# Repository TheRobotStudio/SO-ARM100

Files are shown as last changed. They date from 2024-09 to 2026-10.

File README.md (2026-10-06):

<div align="center">

   <h1>Standard Open SO-100 & SO-101 Arms</h1>
   <div style="display: flex; gap: 1rem; justify-content: center; align-items: center;" >
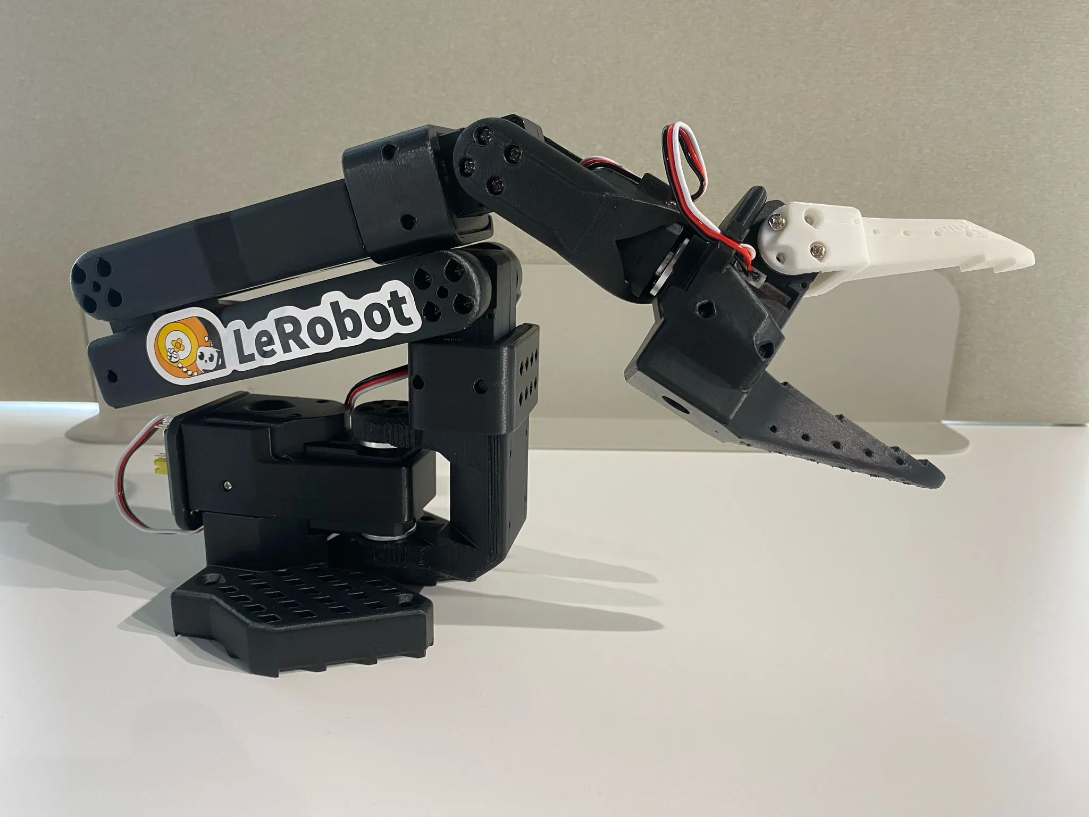
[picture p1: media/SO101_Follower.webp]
SO-101 follower arm
   
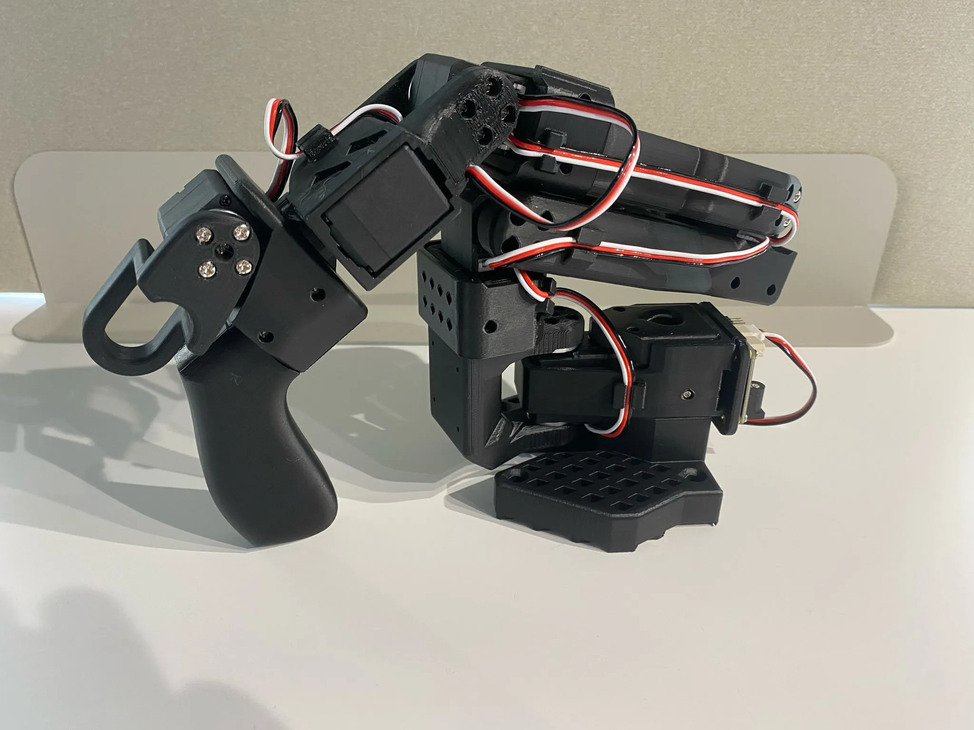
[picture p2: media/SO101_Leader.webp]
SO-101 leader arm
   
</div>

<h2>
    <p>Build Your Own SO-101 Robot!</p>
</h2>

The SO‑101 is the next‑generation version of the SO‑100 robot arm, originally designed by the [RobotStudio](https://www.therobotstudio.com) in collaboration with [Hugging Face](https://huggingface.co/lerobot). It has improved wiring, is easier to assemble (no gear removal) and uses updated motors for the leader arm.

These arms are designed to work seamlessly with the open‑source 🤗 LeRobot library. Join our community on [Discord](https://discord.gg/ggrqhPTsMe) to collaborate on both hardware and software, and help make end‑to‑end AI for robotics more accessible.

</div>

### Documentation 📖
- For the SO‑101 docs, follow this page further.
- Here you can find the [SO‑100 docs](SO100.md) which is deprecated.

### Getting Your Own SO‑101 
You have two options:
- **Build it Yourself**
   - Source the components from the [Bill of Materials](#sourcing-parts).
   - 3D print the parts (or order the 3D printed parts), explained in [Printing the Parts](#printing-the-parts).
   - Follow our [Assembly Guide](https://huggingface.co/docs/lerobot/so101).
- **Buy a Kit**
   - Buy assembled arms or a parts kit from one of the vendors [here](#kits).
   - Optionally follow our [Assembly Guide](https://huggingface.co/docs/lerobot/so101).

### Setup with LeRobot 🤗
After sourcing all parts you can setup your SO-101 with LeRobot [tutorial](https://huggingface.co/docs/lerobot/so101). 

### Optional Hardware 🔧
This repository also includes a range of optional hardware designs such as a raised leader base and different camera mounts. Here you can explore the [full list](#optional-hardware).

## Kits

You can find all optional for SO-100/SO-101 kits here:

- from Seeed studio :earth_africa: [International](https://www.seeedstudio.com/SO-ARM100-Low-Cost-AI-Arm-Kit.html) or :cn: [China](https://item.taobao.com/item.htm?id=878010637397&skuId=5915703371829&spm=a213gs.v2success.0.0.4cbf4831mkqWLn) or :jp: [Akizuki Denshi](https://akizukidenshi.com/catalog/g/g131169/) or [Aliexpress](https://www.aliexpress.com/item/3256808696884714.html?gatewayAdapt=4itemAdapt) (They include **3d printed kits**)
- from WowRobo :earth_africa: [International](https://shop.wowrobo.com/products/so-arm101-diy-kit-assembled-version-1) or :cn: [China](https://item.taobao.com/item.htm?ft=t&id=860171734711) (They include **assembled** versions)
- from RobotEd :switzerland: [Switzerland](https://roboted.ch/en/shop/so-101-robot-arm-kit) (They include **3d printed frame kits**, **electronics kits** and **complete arm kits**)
- from Robonine :earth_africa: [International](https://robonine.com/shop/so-arm101-black-white-robotic-arm-kit/) (They include **parts** kits with a wrist camera and an ArUco cube)
- from PartaBot :us: [US](https://partabot.com) (They include **assembled** versions, and also sell LeKiwi and Koch robots)
- from ForgeMotion Labs :us: [US](https://forgemotionlabs.com/products) or [Amazon US](https://www.amazon.com/s?me=A3TE39P97BKL59) (They include **3d printed frame kits**, **electronics kits** and **complete arm kits**)
- from RoboSEasy :kr: [South Korea](https://smartstore.naver.com/roboseasy)
- from NeoBot :cn: [China](https://item.taobao.com/item.htm?ft=t&id=957685951340)
- from Autodiscovery :eu: [EU](https://autodiscovery.eu/en/products/so-101-kit??utm_source=hf&utm_medium=shop&utm_content=web)

Additionally you can find SO-100 follower arm kit (without leader arm) on [Phospho](https://robots.phospho.ai). It can be especially useful if you own a VR headset.

## Sourcing Parts

The follower and leader arm for this teleoperation setup will almost the same off the shelf parts (except for the motors). If you plan on creating the classic teleoperation set up to be used with the `LeRobot` library please buy from the Parts for Two Arms below. 

We only have links for US, EU, CN, and JP for now. If you find links for other countries, please create an issue or PR so that we add them to the list. Note that prices and items may vary depending on geographic location.

> [!IMPORTANT]  
> The STS3215 motors for the follower arm comes in two sizes. The 7.4V has a stall torque of 16.5kg.cm at 6V (and likely slightly less for a 5V power supply). The 12V version has a stall torque of 30kg.cm. While we found the 7.4V to be sufficient, if you would like more powerful motors you can buy the 12V version [here](https://www.alibaba.com/product-detail/6PCS-12V-30KG-STS3215-High-Torque_1601216757543.html). Note if you do this, you will also have to buy a 12V 5A+ power supply instead of a 5V one. The leader arm is always 7.4V for the SO101.

#### Parts For Two Arms (Follower and Leader Setup):

| Part | Amount | Unit Cost (US) | Buy US | Unit Cost (EU) | Buy EU | Unit Cost (RMB) | Buy CN | Unit Cost (JPY) | Buy JP |
| --- | --- | --- | --- | --- | --- | --- | --- | --- | --- |
| STS3215 Servo 7.4V, 1/345 gear (C001) **<sup>[2](#leaderbundle)</sup>  | 7 | $13.89 | [Alibaba](https://www.alibaba.com/product-detail/Top-Seller-Low-Cost-Feetech-STS3215_1600999461525.html) | €12.2 | [Alibaba](https://www.alibaba.com/product-detail/Top-Seller-Low-Cost-Feetech-STS3215_1600999461525.html) | ￥97.72 | [TaoBao](https://item.taobao.com/item.htm?id=712179366565&skuId=5268252241438)  | ￥2,980 | [Akizuki Denshi](https://akizukidenshi.com/catalog/g/g116312/)  |
| STS3215 Servo 7.4V, 1/191 gear (C044) **<sup>[2](#leaderbundle)</sup> | 2 | $13.89 | [Alibaba](https://www.alibaba.com/product-detail/Feetech-STS3215-SO-ARM101-Servo-7_1601430747897.html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) | €12.2 | [Alibaba](https://www.alibaba.com/product-detail/Feetech-STS3215-SO-ARM101-Servo-7_1601430747897.html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) | ￥97.72 | -  | ￥2,980 | [Akizuki Denshi](https://akizukidenshi.com/catalog/g/g131131/)  |
| STS3215 Servo 7.4V, 1/147 gear (C046) **<sup>[2](#leaderbundle)</sup> | 3 | $13.89 | [Alibaba](https://www.alibaba.com/product-detail/Feetech-STS3215-SO-ARM101-Servo-7_1601430760797.html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) | €12.2 | [Alibaba](https://www.alibaba.com/product-detail/Feetech-STS3215-SO-ARM101-Servo-7_1601430760797.html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) | ￥97.72 | -  | ￥2,980 | [Akizuki Denshi](https://akizukidenshi.com/catalog/g/g131132/)  |
| Motor Control Board | 2 | $10.6 | [Amazon](https://www.amazon.com/Waveshare-Integrates-Control-Circuit-Supports/dp/B0CTMM4LWK/) | €11.4 | [Amazon](https://www.amazon.fr/-/en/dp/B0CJ6TP3TP/) | ￥27 | [TaoBao](https://detail.tmall.com/item.htm?id=738817173460&skuId=5096283384143) | ￥980 | [Akizuki Denshi](https://akizukidenshi.com/catalog/g/g131227/)  |
| USB-C Cable 2 pcs | 1 | $7 | [Amazon](https://www.amazon.com/Charging-etguuds-Charger-Braided-Compatible/dp/B0B8NWLLW2/?th=1) | €7 | [Amazon](https://www.amazon.fr/dp/B07BNF842T/) | ￥23.9\*2 | [TaoBao](https://detail.tmall.com/item.htm?id=44425281296&skuId=5611379016222)  | ￥1,498 | [Amazon](https://www.amazon.co.jp/dp/B0C3H9L6KZ)  |
| Power Supply | 2 | $10 | [Amazon](https://www.amazon.com/Facmogu-Switching-Transformer-Compatible-5-5x2-1mm/dp/B087LY41PV/) | €15.7 | [Amazon](https://www.amazon.fr/-/en/dp/B01HRR9GY4/) | ￥22.31 | [TaoBao](https://item.taobao.com/item.htm?id=544824248494&skuId=4974994129990)  | ￥1,550 | [Akizuki Denshi](https://akizukidenshi.com/catalog/g/g106238/)  |
| Table Clamp 4pcs | 1 | $9 | [Amazon](https://www.amazon.com/TAODAN-Trigger-Ratchet-Woodworking-Processes/dp/B0DJNXF8WH?rps=1&sr=1-18) | €9.7 | [Amazon](https://www.amazon.fr/Connex-COXT865210-Lot-Serre-joints-bricolage/dp/B00NA3T2CQ) | ￥5.2*4 | [TaoBao](https://detail.tmall.com/item.htm?id=801399113134&skuId=5633627126649) | ￥2,200 | [Amazon](https://www.amazon.co.jp/dp/B0DJNXF8WH)  |
| Screwdriver Set<sup>[1](#myfootnote1)</sup> | 1 | $6 | [Amazon](https://www.amazon.com/Precision-Phillips-Screwdriver-Electronics-Computer/dp/B0DB227RTH) | €9 | [Amazon](https://www.amazon.fr/Vinabo-Magnétique-Electronique-Réparation-Informatique/dp/B0BNQBNFFJ) | ￥14.9 | [TaoBao](https://detail.tmall.com/item.htm?id=675684600845&skuId=4856851392176) | ￥500 | [Amazon](https://www.amazon.co.jp/dp/B01MDNJVMN)  |
| Total | --- | $229.88 | --- | €226.3 | --- | ￥1343.16 | --- | ￥44,530 | --- |

<a name="leaderbundle">2</a>: You can buy **all six STS3215 servos needed for the SO-101 leader arm**  
(3 × 1/147 gear (C046), 2 × 1/191 gear (C044), 1 × 1/345 gear (C001)) in a single bundle on [Alibaba](https://www.alibaba.com/product-detail/6PCS-7-4V-STS3215-Servos-for_1601428584027.html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).

#### Parts for One Follower Arm:

| Part | Amount | Unit Cost (US) | Buy US | Unit Cost (EU) | Buy EU | Unit Cost (RMB) | Buy CN | Unit Cost (JPY) | Buy JP |
| --- | --- | --- | --- | --- | --- | --- | --- | --- | --- |
| STS3215 Servo 7.4V, 1/345 gear (C001) | 6 | $13.89 | [Alibaba](https://www.alibaba.com/product-detail/Top-Seller-Low-Cost-Feetech-STS3215_1600999461525.html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) | €12.2 | [Alibaba](https://www.alibaba.com/product-detail/Top-Seller-Low-Cost-Feetech-STS3215_1600999461525.html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) | ￥97.72 | [TaoBao](https://item.taobao.com/item.htm?id=712179366565&skuId=5268252241438)  | ￥2,980 | [Akizuki Denshi](https://akizukidenshi.com/catalog/g/g116312/)  |
| Motor Control Board | 1 | $10.6 | [Amazon](https://www.amazon.com/Waveshare-Integrates-Control-Circuit-Supports/dp/B0CTMM4LWK/) | €11.4 | [Amazon](https://www.amazon.fr/-/en/dp/B0CJ6TP3TP/) | ￥27 | [TaoBao](https://detail.tmall.com/item.htm?id=738817173460&skuId=5096283384143) | ￥980 | [Akizuki Denshi](https://akizukidenshi.com/catalog/g/g131227/)  |
| USB-C Cable 2 pcs | 1 | $7 | [Amazon](https://www.amazon.com/Charging-etguuds-Charger-Braided-Compatible/dp/B0B8NWLLW2/?th=1) | €7 | [Amazon](https://www.amazon.fr/dp/B07BNF842T/) | ￥23.9 | [TaoBao](https://detail.tmall.com/item.htm?id=44425281296&skuId=5611379016222)  | ￥1,498 | [Amazon](https://www.amazon.co.jp/dp/B0C3H9L6KZ)  |
| Power Supply | 1 | $10 | [Amazon](https://www.amazon.com/Facmogu-Switching-Transformer-Compatible-5-5x2-1mm/dp/B087LY41PV/) | €15.7 | [Amazon](https://www.amazon.fr/-/en/dp/B01HRR9GY4/) | ￥22.31 | [TaoBao](https://item.taobao.com/item.htm?id=544824248494&skuId=4974994129990)  | ￥1,550 | [Akizuki Denshi](https://akizukidenshi.com/catalog/g/g106238/)  |
| Table Clamp 2pcs | 1 | $5 | [Amazon](https://www.amazon.com/Mr-Pen-Carpenter-Clamp-6inch/dp/B092L925J4/) | €8 | [Amazon](https://www.amazon.fr/-/en/dp/B08HZ1QRBF/) | ￥7.8 | [TaoBao](https://detail.tmall.com/item.htm?id=738636473238&skuId=5505939904942) | ￥2,200 | [Amazon](https://www.amazon.co.jp/dp/B0DJNXF8WH)  |
| Screwdriver Set<sup>[1](#myfootnote1)</sup> | 1 | $6 | [Amazon](https://www.amazon.com/Precision-Phillips-Screwdriver-Electronics-Computer/dp/B0DB227RTH) | €9 | [Amazon](https://www.amazon.fr/Vinabo-Magnétique-Electronique-Réparation-Informatique/dp/B0BNQBNFFJ) | ￥14.9 | [TaoBao](https://detail.tmall.com/item.htm?id=675684600845&skuId=4856851392176) | ￥500 | [Amazon](https://www.amazon.co.jp/dp/B01MDNJVMN)  |
| Total | --- | $121.94 | --- | €124.3 | --- | ￥682.23 | --- | ￥24,414 | --- |

<a name="myfootnote1">1</a>: You do not need to use this exact screwdriver set, but it is highly recommended to have phillips head screw driver sizes #0 and #1 for easiest screw installation and removal. These are both standard sizes which will likely appear in most small screwdriver sets.

## Printing the Parts

A variety of 3D printers are acceptable to print the parts necessary of the follower and leader arm. Follow the steps below to ensure a good print.

### Step 1: Choose a Printer
The STL files provided are ready to print on many FDM printers. Below are the tested and suggested settings though others may work.
   1. Material: PLA+
   2. Nozzle Diameter and Precision: 0.4mm nozzle diameter at 0.2mm layer height or 0.6mm nozzle at 0.4mm layer height.
   3. Infill Density: 15%
   4. Sample Printers: [Prusa MINI+](https://www.prusa3d.com/product/original-prusa-mini-semi-assembled-3d-printer-4/), [UP Plus 2](https://shop.tiertime.com/product/tiertime-up-plus-2-3d-printer/), [Creality Ender 3](https://www.amazon.com/Comgrow-Creality-Ender-Aluminum-220x220x250mm/dp/B07BR3F9N6/), [Bambu Lab A/P/X-series](https://bambulab.com)

### Step 2: Set up the Printer
   1. Ensure that the printer is calibrated and the bed level is correctly set using the printer specific instructions.
   2. Clean the print bed, making sure it is free from dust, or grease. If cleaning the bed using water, or other liquid, dry the bed.
   3. If your printer recommends it, use a standard glue stick and apply a thin, even layer of glue across the print area of the bed. Avoid clumping or uneven application.
   4. Load the printer filament using printer specific instructions.
   5. Ensure the printer settings match the ones suggested above (most printers have multiple settings so choose the ones that most closely match).
   6. Set for supports everywhere but ignore slopes greater than 45 degrees to the horizontal.
   7. There should be no supports in the screw holes with horizontal axes.
### Step 3: Check Printer Accuracy
   1. In the [Gauges](STL/Gauges) folder, there are two types of gauges, one to check the size of print against a standard 4x2 lego block and one against a STS3215 servo.
      1. If you have a STS3215 servo, print:
         1. [Gauge Zero](STL/Gauges/Gauge_0.STL)
         2. [Gauge Tight](STL/Gauges/Gauge_tight_1.STL)
      2. If you have a standard lego block, print:
         1. [Gauge Zero](STL/Gauges/Lego_Size_Test_02_zero.STL)
         2. [Gauge -0.1](STL/Gauges/Lego_Size_Test_02_minuspoint1.STL)
   2. Test the gauge 0 against your given object (Lego or Servo). The fit should be similar to this [tutorial](https://youtu.be/dss8E3DG2rA).
   3. If the fit is appropriate, go onto Step 4, otherwise, change your printer settings and try again or create an issue.
### Step 4: Print the Parts
All the parts for the leader or follower are for easy 3D printing already contained in a **single file**, correctly orientated for z upwards to minimize supports.
   1. For printer bed sizes of 220mmx220mm (such as the Ender), print these files:
      - [Follower](STL/SO101/Follower/Ender_Follower_SO101.stl)
      - [Leader](STL/SO101/Leader/Ender_Leader_SO101.stl)
   2. For printer bed sizes of 205mm x 250mm (such as the Prusa/Up):
      1. [Follower](STL/SO101/Follower/Prusa_Follower_SO101.stl)
      2. [Leader](STL/SO101/Leader/Prusa_Leader_SO101.stl)

This table contains all individual files:
<details>
<summary>Individual Part Files</summary>

#### Common Parts

| Part | Link |
|---|---|
| Base_motor_holder_SO101.stl | [Base_motor_holder_SO101.stl](STL/SO101/Individual/Base_motor_holder_SO101.stl) |
| Base_SO101.stl | [Base_SO101.stl](STL/SO101/Individual/Base_SO101.stl) |
| Motor_holder_SO101_Base.stl | [Motor_holder_SO101_Base.stl](STL/SO101/Individual/Motor_holder_SO101_Base.stl) |
| Motor_holder_SO101_Wrist.stl | [Motor_holder_SO101_Wrist.stl](STL/SO101/Individual/Motor_holder_SO101_Wrist.stl) |
| Under_arm_SO101.stl | [Under_arm_SO101.stl](STL/SO101/Individual/Under_arm_SO101.stl) |
| Upper_arm_SO101.stl | [Upper_arm_SO101.stl](STL/SO101/Individual/Upper_arm_SO101.stl) |
| Rotation_Pitch_SO101.stl | [Rotation_Pitch_SO101.stl](STL/SO101/Individual/Rotation_Pitch_SO101.stl) |
| Wrist_Roll_Pitch_SO101.stl | [Wrist_Roll_Pitch_SO101.stl](STL/SO101/Individual/Wrist_Roll_Pitch_SO101.stl) |
| WaveShare_Mounting_Plate_SO101.stl  | [WaveShare_Mounting_Plate_SO101.stl](STL/SO101/Individual/WaveShare_Mounting_Plate_SO101.stl) |

#### Leader‑Specific Parts

| Part | Link |
|---|---|
| Handle_SO101.stl | [Handle_SO101.stl](STL/SO101/Individual/Handle_SO101.stl) |
| Trigger_SO101.stl | [Trigger_SO101.stl](STL/SO101/Individual/Trigger_SO101.stl) |
| Wrist_Roll_SO101.stl  | [Wrist_Roll_SO101.stl](STL/SO101/Individual/Wrist_Roll_SO101.stl) |

#### Follower‑Specific Parts

| Part | Link |
|---|---|
| Moving_Jaw_SO101.stl | [Moving_Jaw_SO101.stl](STL/SO101/Individual/Moving_Jaw_SO101.stl) |
| Wrist_Roll_Follower_SO101.stl | [Wrist_Roll_Follower_SO101.stl](STL/SO101/Individual/Wrist_Roll_Follower_SO101.stl) |
</details>

### Step 5: Remove Supports
   1. After the print is done, use a putty knife to scrape the the parts off the print bed.
   2. Remove any support material from parts.

### Don't Own a 3D printer?
Go here: [Printing services](./3DPRINT.md)

## Optional Hardware
<!--Note: no hardware emoji here so links work correctly-->
Extend your SO‑100/SO‑101 with these add-ons.
<details>
<summary>Add‑ons</summary>

#### 0. XLeRobot

A dual-arm mobile robot for daily use, with 2x SO101 arms, 1x Lekiwi base, 1x 300Wh Anker Battery, 2x wrist RGB cameras, 1x head depth camera (with a 2-dof neck). Total cost 660$.

82c2b72eab7c716b90fafac0a9caf895

[→ Full Documentation](https://xlerobot.readthedocs.io/en/latest/index.html), with detailed BOM, 3D printing models, assembly guide, simulation, and teleop guide.

#### 1. Mount Helper  
Print the handy mount jig for easier alignment during assembly.  

[→ View README](Optional/Mount_Helper/README.md)

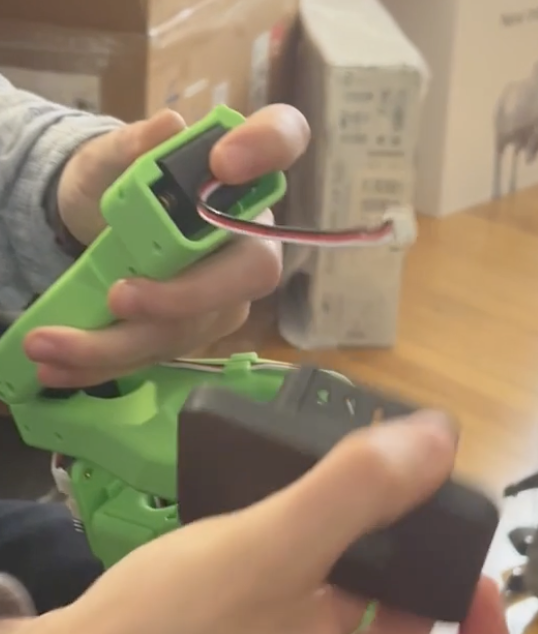
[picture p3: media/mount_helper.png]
Mount Helper


#### 2. Overhead Camera Mount 

For bird’s‑eye views in single or bi‑manual setups.  
(SO100/101)

| Webcam  | 32×32 Cam Module |
|:---:|:---:|
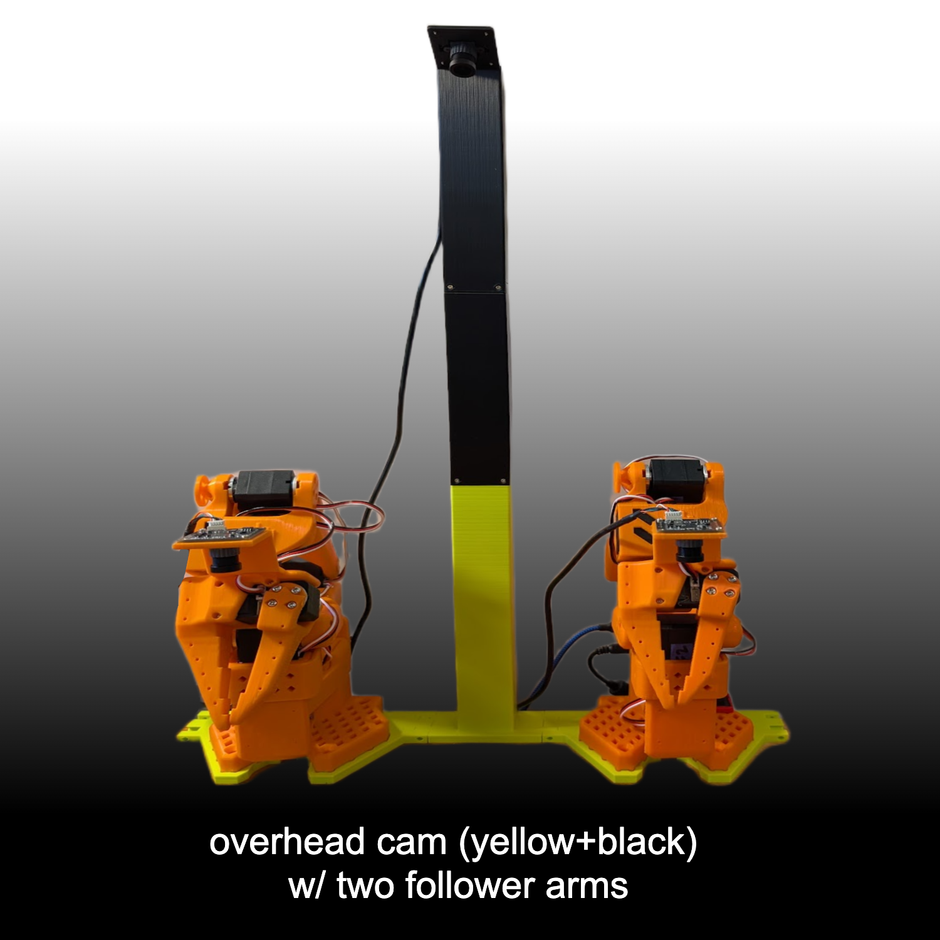
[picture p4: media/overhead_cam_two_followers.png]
 |  
| [Instructions](Optional/Overhead_Cam_Mount_Webcam/README.md) | [Instructions](Optional/Overhead_Cam_Mount_32x32_UVC_Module/README.md) 

#### 3. Base Mounts

| Raised Leader Base | 4040 Aluminum Profile Mount |
|:---:|:---:|
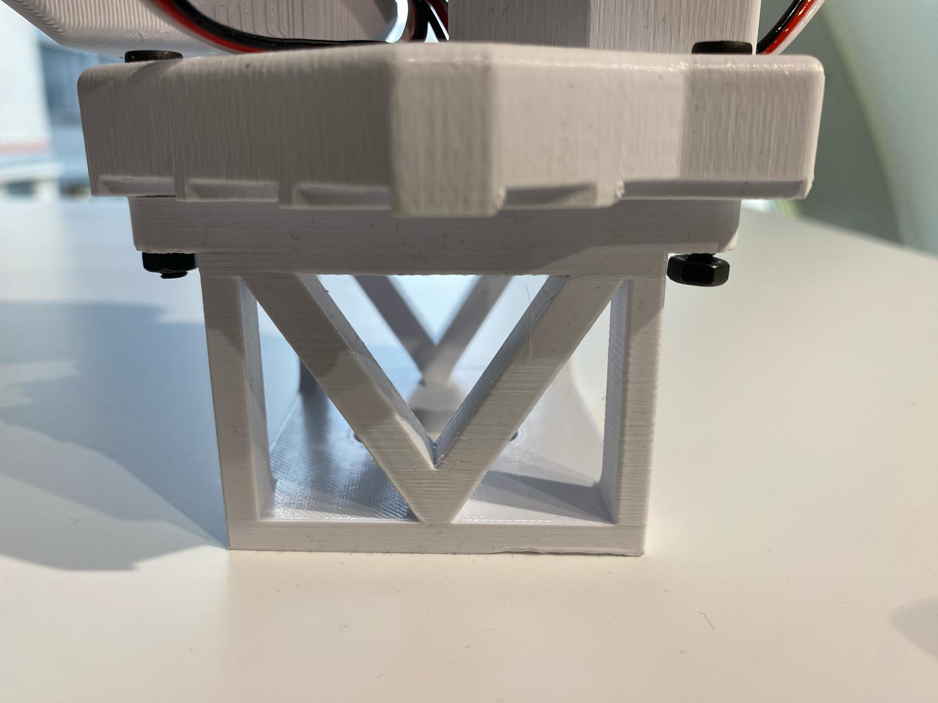
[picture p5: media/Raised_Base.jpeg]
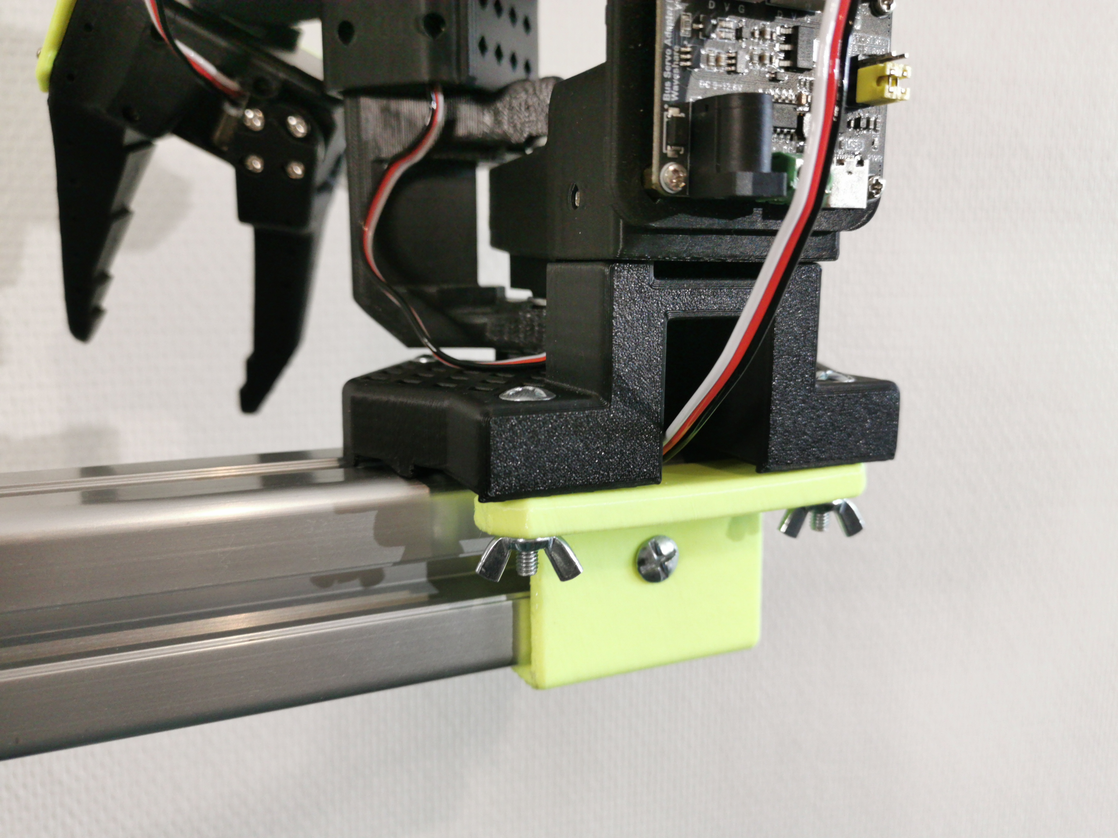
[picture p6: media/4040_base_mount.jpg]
 |   
[Download STL](Optional/Raised_Base/Raised_Base_Extension.stl) | [Instructions](Optional/4040_Base_Mount/README.md)

#### 4. Tactile Sensing (AnySkin)  
Add touch sensing to your gripper.  

[→ Find on WOWROBO](https://shop.wowrobo.com/products/enhanced-anyskin-premium-crafted-editionwowskin)

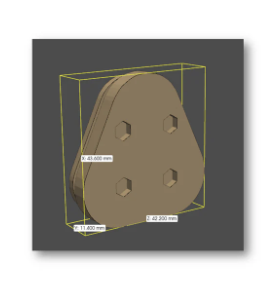
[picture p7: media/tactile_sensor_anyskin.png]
AnySkin Sensor


#### 5. Wrist‑Mount Cameras

| 32×32 UVC Hex Nut (SO101) | 32×32 UVC Integrated (SO100/101) | 32×32 UVC Plug‑on | RealSense D405 | RealSense D435/D435I | Webcam (Vinmooog) |
| --- | --- | --- | --- | --- | --- |
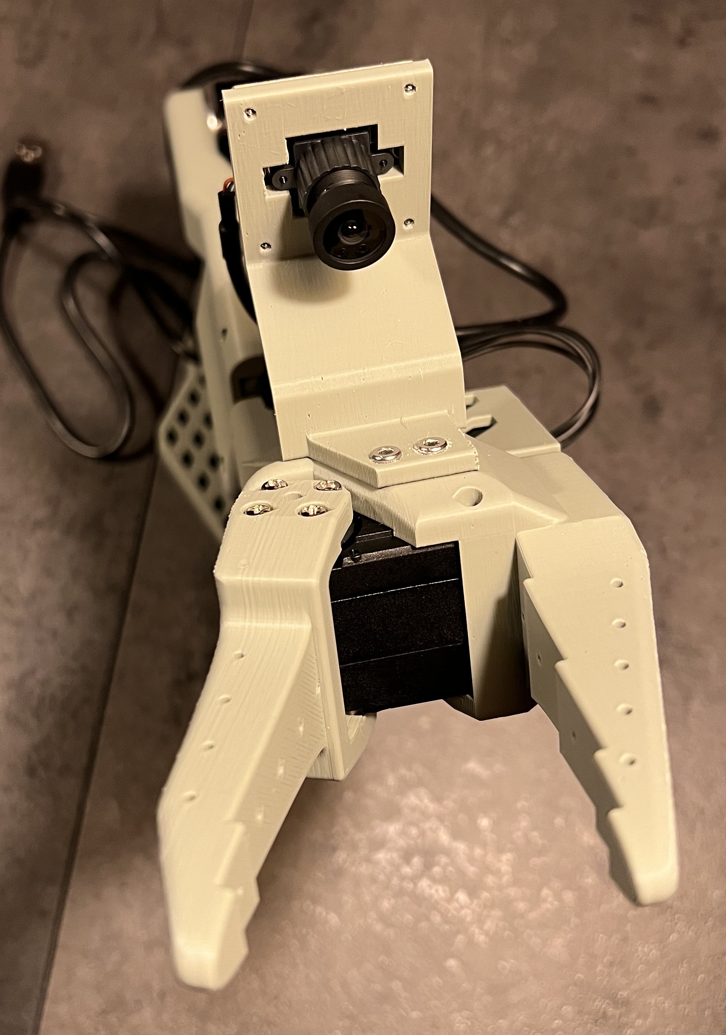
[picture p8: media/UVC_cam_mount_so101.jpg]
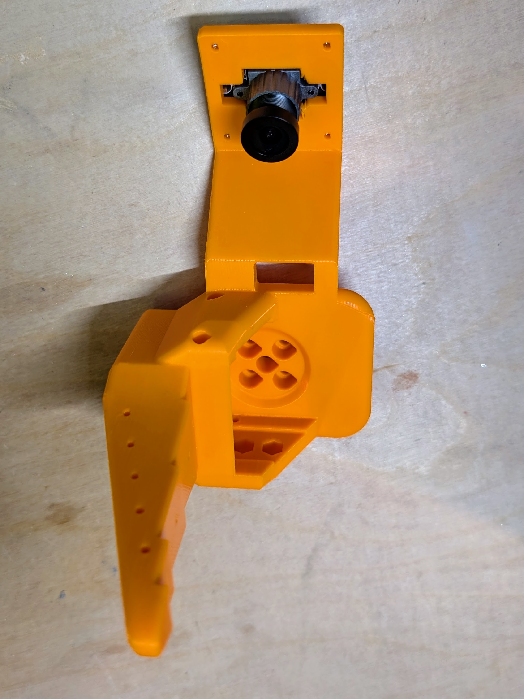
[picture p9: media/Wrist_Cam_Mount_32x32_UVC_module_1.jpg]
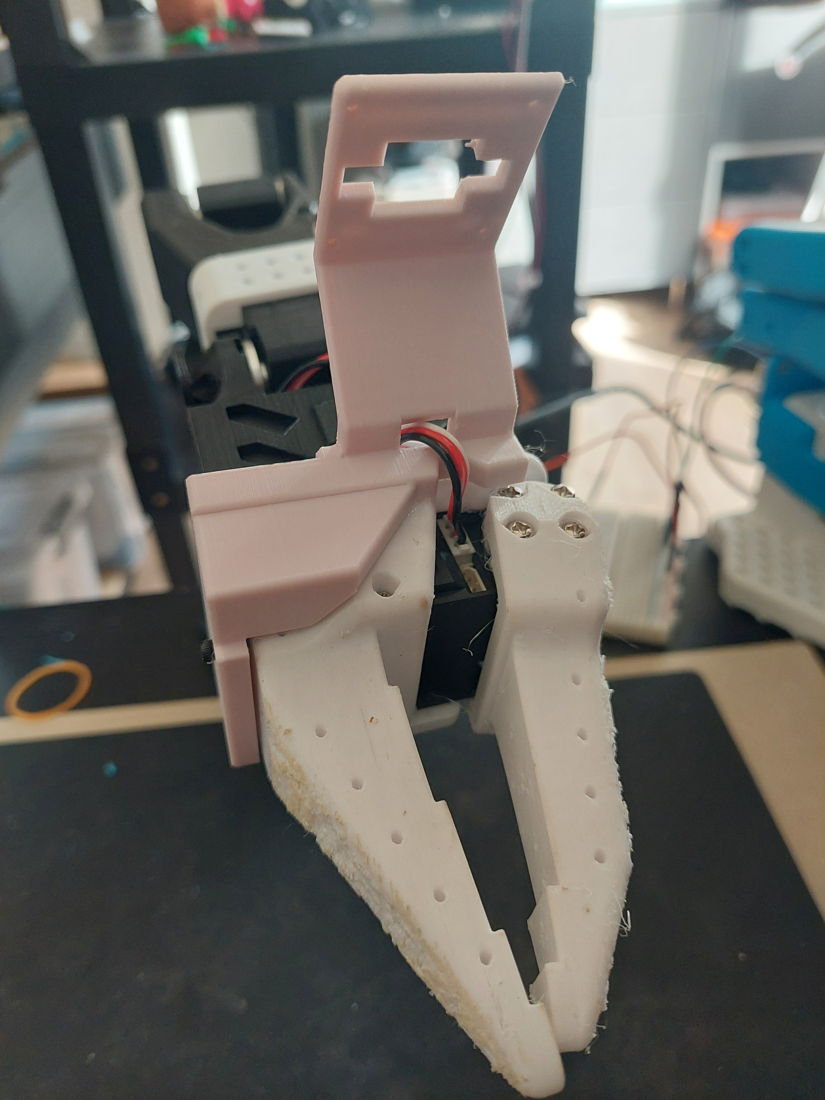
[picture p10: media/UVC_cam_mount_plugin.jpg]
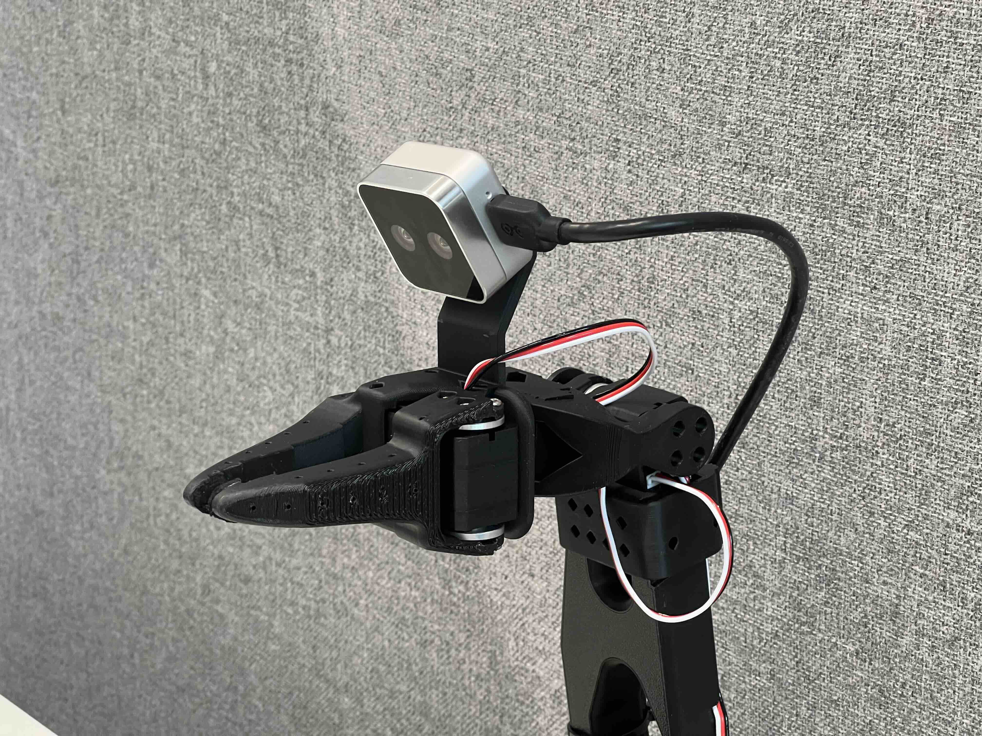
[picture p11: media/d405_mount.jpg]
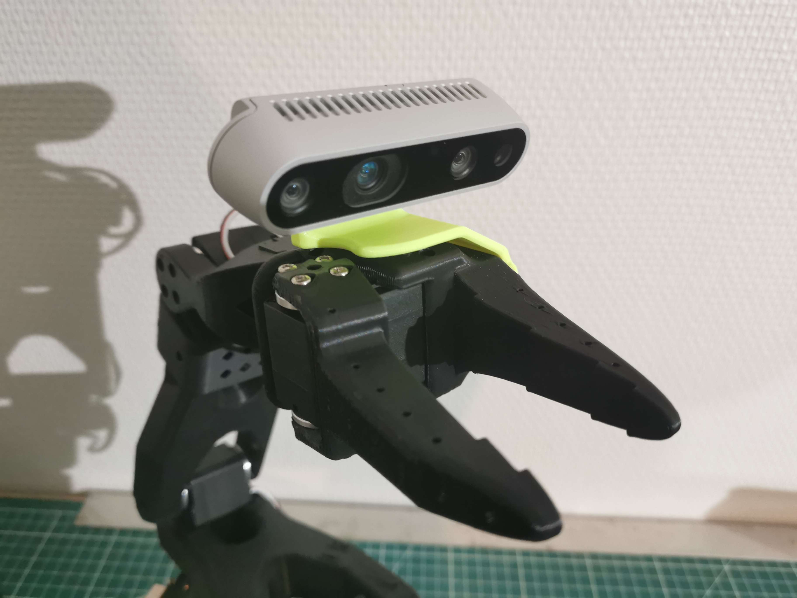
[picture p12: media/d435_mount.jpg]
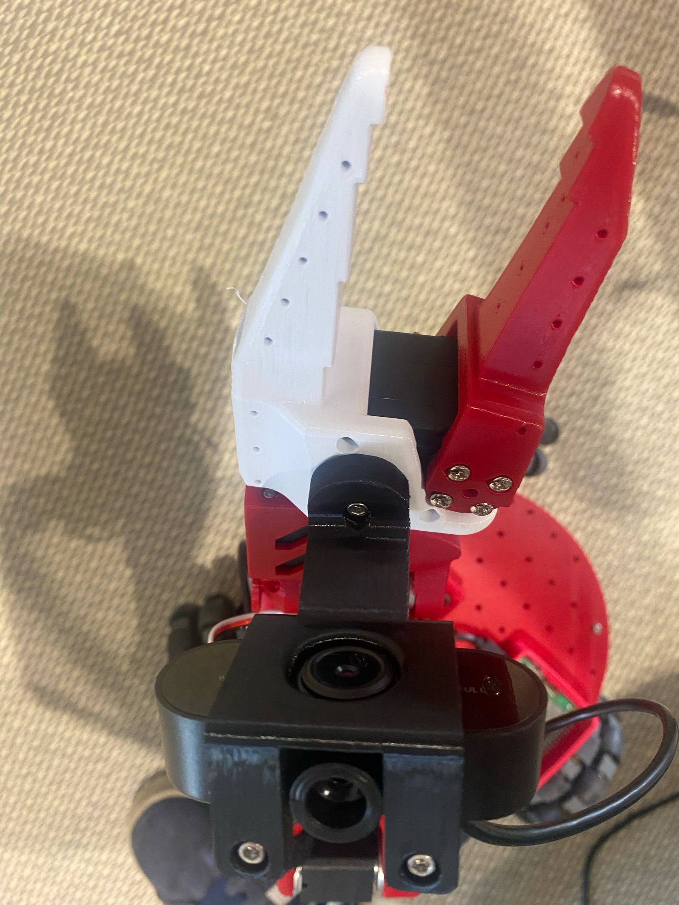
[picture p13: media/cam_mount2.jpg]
|  |  |  |  |  |  |
| [Instructions](Optional/SO101_Wrist_Cam_Hex-Nut_Mount_32x32_UVC_Module) | [Instructions](Optional/Wrist_Cam_Mount_32x32_UVC_Module/README.md) | [Instructions](Optional/Wrist_Cam_Plug_Mount_32x32_UVC_Module) | [Instructions](Optional/Wrist_Cam_Mount_RealSense_D405) | [Instructions](Optional/Wrist_Cam_Mount_RealSense_D435) | [Instructions](Optional/Wrist_Cam_Mount_Vinmooog_Webcam) |

#### 6. Compliant Gripper
Add some flexibility to your gripper by downloading the compliant gripper parts and printing them using a flexible filament like TPU 95A. 

[→ View README](Optional/Compliant_Gripper/README.md). 



#### 7. Compliant Gripper (new)
Printed with TPU 95A for the finger and PLA for the base. 
Better structure and better grasp (both precision and power). No need to print support for the TPU finger. Requires 2 additional M3 screws, optional 3M gripper tape for higher friction.
d2e57534a9e55a3d4dc0d644242cd044

[→ Find on XLeRobot](https://github.com/Vector-Wangel/XLeRobot/tree/main/hardware)
</details>

## Debugging Motors
For debugging, any Windows PC can connect over USB to program the servos and to debug or do tests. To do so download [Feetech Software](https://www.feetechrc.com/software.html). For Ubuntu, you can use [FT_SCServo_Debug_Qt](https://github.com/Kotakku/FT_SCServo_Debug_Qt). Note: This step is not necessary as motors can be configured using the LeRobot Library, but this can be helpful for debugging.

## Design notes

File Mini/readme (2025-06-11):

This is an experiment in printing the entire SO-Arm as a single piece that can then articulate once the supports are removed.
The clearances are only 0.2mm between all parts which has proven to be ok in test pieces, but I find hard to believe will work on the whole thing.
I shall know by tomorrow morning whether it will move after printing on a Bambu A1, with a 0.4mm brass nozzle, 0.2mm layer thickness with supports above 30degrees in light green PLA+.
Yes, the colour of PLA effects the end result. Probably due to subtle chemical differences in the dyes but I've no clear hard evidence or research to support this guess.
I'd welcome any feedback on different machines and settings and whether the finished print can be made to move freely with the present clearance between parts.

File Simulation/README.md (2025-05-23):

# Simulation Models for SO100 and SO101

This folder contains simulation files for the **SO100** and **SO101**.

## SO100

- Contains a single **URDF** file for the SO100 robot.
- To visualize the **URDF**, you can use [rerun](https://www.rerun.io/) along with the [URDF visualizer plugin](https://github.com/rerun-io/rerun-loader-python-example-urdf#installing-the-plugin)

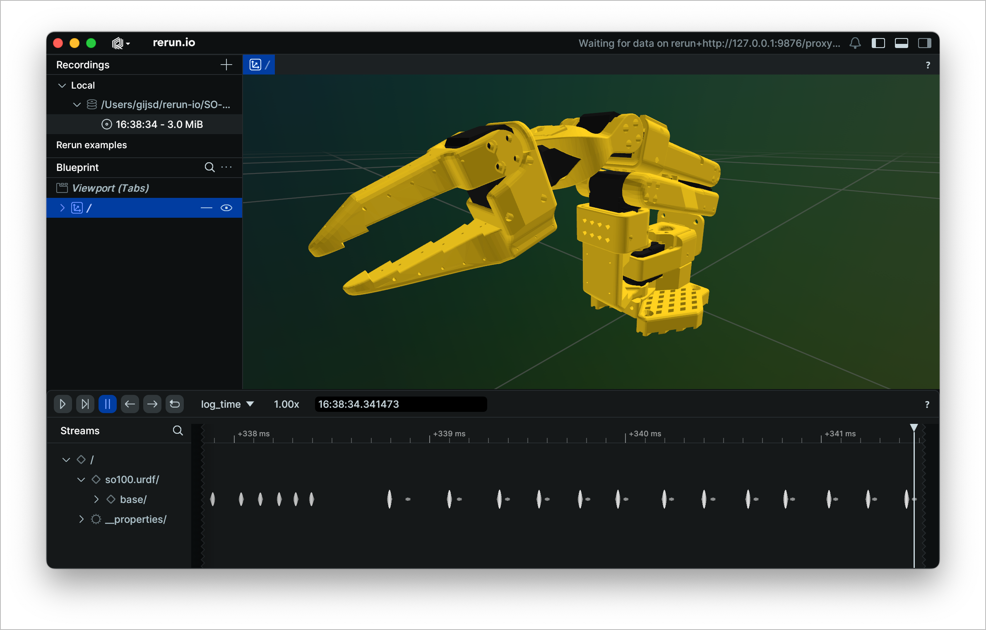
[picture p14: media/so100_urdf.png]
SO100


```bash
rerun Simulation/SO100/so100.urdf
````

## SO101

- Contains both **URDF** and **MJCF** (MuJoCo) files for simulation.
- To visualize the **URDF** files, you can use [rerun](https://www.rerun.io/) along with the [URDF visualizer plugin](https://github.com/rerun-io/rerun-loader-python-example-urdf#installing-the-plugin)

```bash
rerun Simulation/SO101/so101_new_calib.urdf
rerun Simulation/SO101/so101_old_calib.urdf
```

- For more details on:
  - The differences between the **old** and **new calibration** URDFs.
  - How the **MJCF** file was generated from the CAD model.

👉 See the file [`Simulation/SO101/README.md`](Simulation/SO101/README.md).

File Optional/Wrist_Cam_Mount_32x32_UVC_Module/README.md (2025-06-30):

# Wrist Camera Integrated/One-Piece Installation Guide for SO-100/SO-101

 
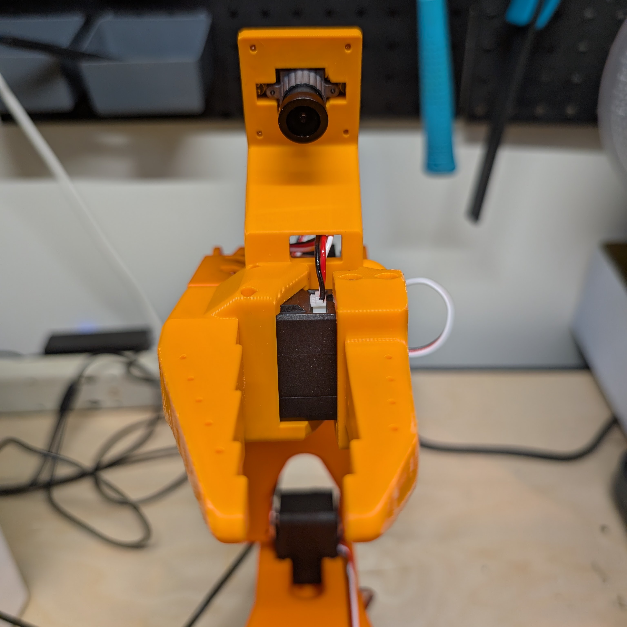
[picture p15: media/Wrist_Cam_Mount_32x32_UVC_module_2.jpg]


## Overview
This guide provides step-by-step instructions for installing a **Wrist Camera** on the SO-100/SO-101 robots using a **Camera Module** and a 3D-printed **Jaw Replacement Part**.

## Comparison to Main Design
#### Advantages:
- smaller
- fewer parts
- no additional screws/hardware needed to attach camera

#### Disdvantages:
- requires removal/replacement of existing **Wrist Roll** vs an add-on

## Required Components
### Hardware:
- **USB Camera Module** (1) - this is the [recommended model](https://www.amazon.com/innomaker-Computer-Raspberry-Support-Windows/dp/B0CNCSFQC1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), but any 32mm x 32mm USB camera module with min 720p / 30 fps spec will likely work
- 3D-printed Wrist Roll Replacement ([SO-100](/Optional/Wrist_Cam_Mount_32x32_UVC_Module/stl/Wrist_Cam_Mount_32x32_UVC_Module_SO100.stl), [SO-101](/Optional/Wrist_Cam_Mount_32x32_UVC_Module/stl/Wrist_Cam_Mount_32x32_UVC_Module_SO101.stl)) (1)
- **M2 Screws** (4) - these are the smaller screws that came with your Feetech servos.

Screenshot 2025-03-04 at 7 43 33 PM

## Assembly Instructions
### Step 1: Replace the [Wrist Roll](../../STL/SO101/Individual/Wrist_Roll_Follower_SO101.stl) with our new one
1. If a [Moving Jaw](../../STL/SO101/Individual/Moving_Jaw_SO101.stl) is already installed on the arm, leave it attached. Remove the gripper servo from the existing Wrist Roll piece by:
 - unscrewing all 6 of **M3 Screws** from the front and back of the servo which attach it to the Wrist Roll piece 
 - gently pulling the motor out
 - unscrew the remaining 4 **M3 Screws** holding the Wrist Roll piece to the next servo
   
2. 3D print the **Wrist Roll Replacement**.

3. Attach the **Wrist Roll Replacement** by doing the reverse of (1).

### Step 2: Install the Camera
1. Take out the **Camera Module**.
2. Align the 4 holes of the **Camera Module** with the **Moving Jaw Replacement**, and attach using 4 **M2 Screws**.



### Step 3: Configure Software and Adjust Focus
1. In your software, set your resolution and FPS. 
- **Note**: You will likely want to set your resolution to *640 x 480* and FPS to *30* even if the camera module's max resolution/frame rate is higher, as most models work with lower resolutions and any higher will just be data bloat.
2. Turn on your arm.  Look at the video feed from your newly installed camera (On Mac, you can also use *QuickTime*->*New Movie Recording* to see this feed).  
3. **Important** - The focus on the camera is manual and will look very blurry initially. Adjust the focus by twisting the lens counterclockwise or clockwise until the video feed is clear.

## Acknowledgements

Design & Testing
- Conor McGartholl
- Philip Fung

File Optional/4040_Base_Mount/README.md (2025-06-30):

## Base Mount for 4040 Aluminum Profiles

<p align="left">
  
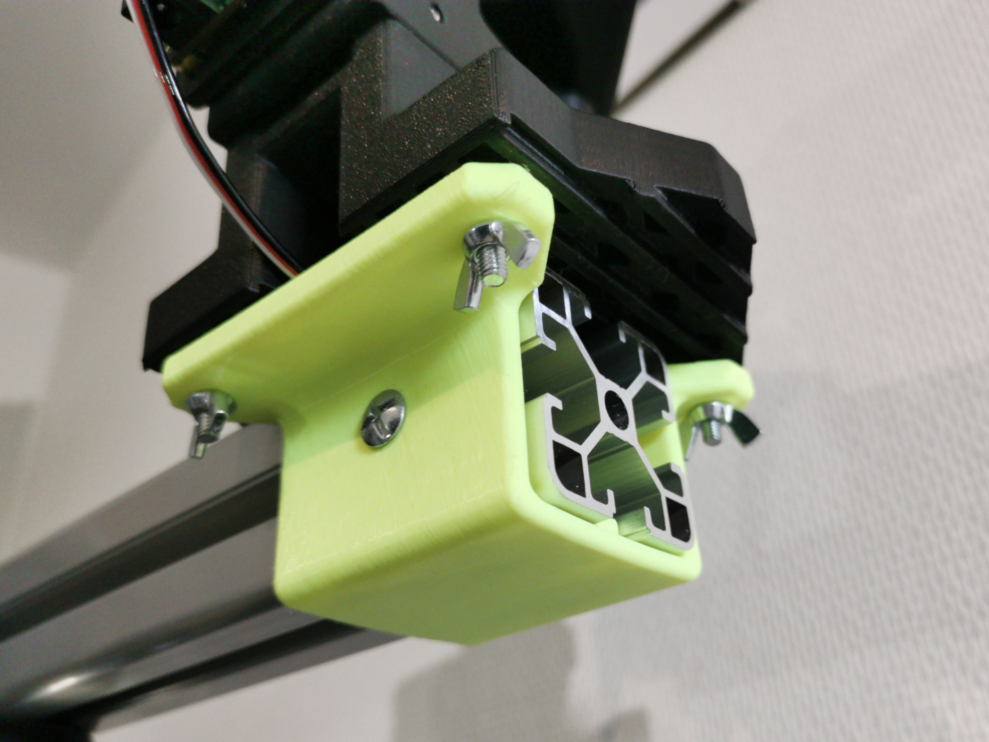
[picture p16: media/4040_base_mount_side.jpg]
  
</p>

This 3D-printed adapter allows you to securely attach your **SO-100 base** to standard **40×40 mm aluminum extrusion profiles** (8.2 mm slot width).  
Perfect for building a sturdy, modular platform for your robotic arm.

- 📦 [Download STL](./stl/4040_base_mount.stl)  
- 📐 [Download STEP](./step/4040_base_mount.step)

### 🛠 Assembly Instructions

- Use **1 × M4×16 mm bolt** and **1 × M4 T-nut (8 mm slot)** to attach the adapter to the aluminum profile.  
- Use **4 × M4×30 mm bolts** and **4 × M4 wing nuts** to secure the **SO-100 base** to the mount.  
> The holes are 5 mm in diameter, so M5 hardware can also be used.

### 🖨 Suggested Print Orientation

For optimal strength, print the part in the orientation shown below.  
> Supports are required.

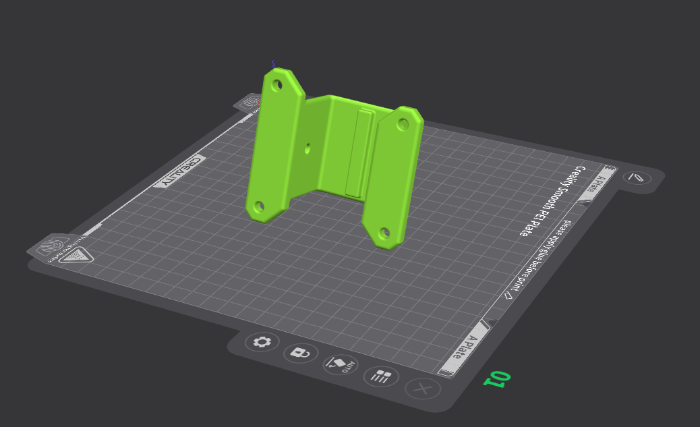
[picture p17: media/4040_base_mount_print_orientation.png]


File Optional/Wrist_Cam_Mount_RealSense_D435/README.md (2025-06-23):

# Wrist Camera Mount for Intel® RealSense™ D435/D435i



This 3D-printed mount lets you easily attach an Intel® RealSense™ D435 or D435i to the **SO-100 wrist** — no modifications or extra hardware required.  
You can reuse the spare screws included with the Feetech servos.

👉 [Download the STL file](stl/Wrist_cam_mount_RealSense_D435.stl)

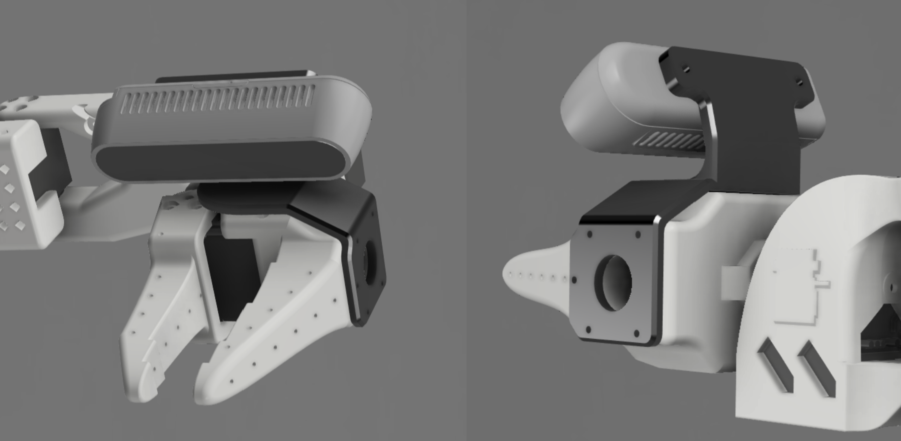
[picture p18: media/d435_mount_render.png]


### Assembly Instructions

- Use **5 small screws** to attach the mount to the SO-100 wrist.  
- Use **2 M3*6mm screws** to secure the Intel camera to the mount.

### Camera Field of View  
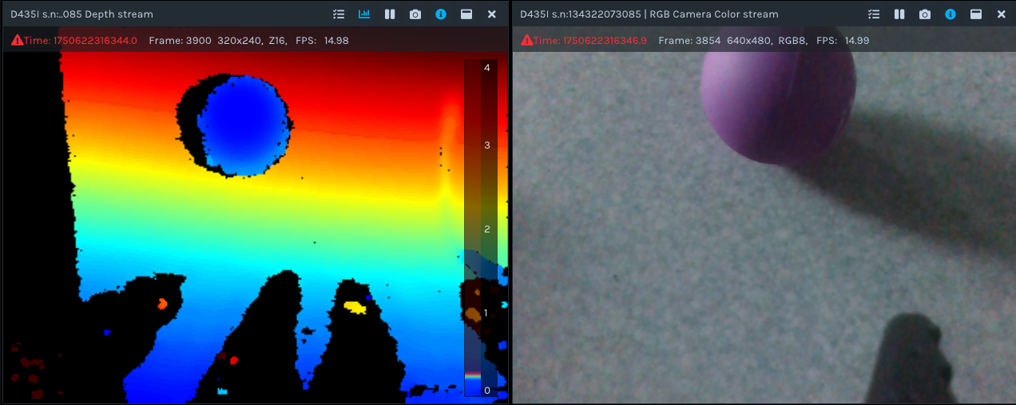
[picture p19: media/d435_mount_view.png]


> 📝 The camera is centered for **depth sensing**, but can also function with **RGB only**.

### Suggested Print Orientation  
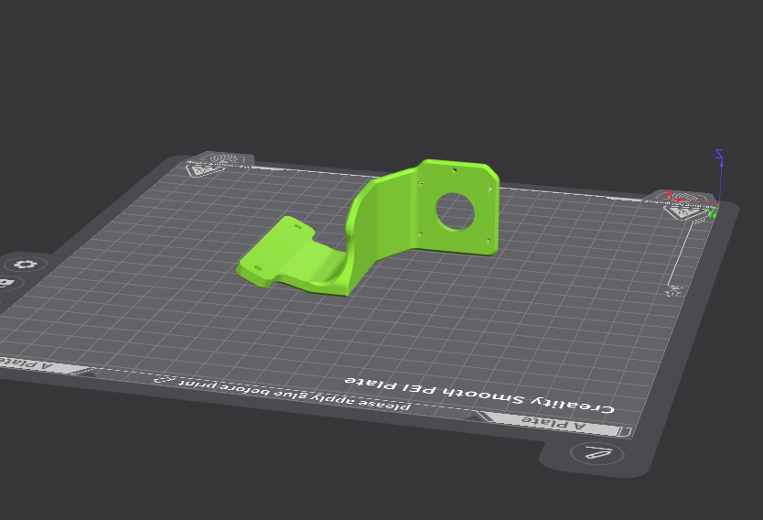
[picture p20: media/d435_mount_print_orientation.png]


## Vinmooog  Adapter (Optional)

You can also use this mount with a **Vinmooog camera** using the adapter below:

👉 [Download the STL file](stl/D435_Vinmooog_adapter.stl)

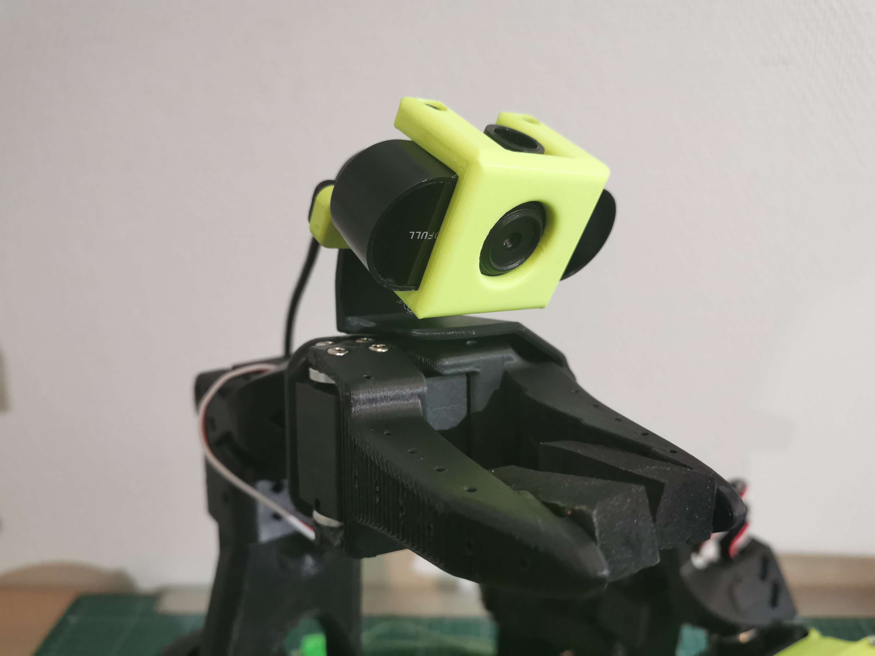
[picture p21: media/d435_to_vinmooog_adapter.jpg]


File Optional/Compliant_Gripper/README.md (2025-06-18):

# Compliant Gripper Guide for the SO-101 Arm



The compliant gripper is a modification of the original rigid gripper that is printed out of a flexible material (TPU). It uses a hollowed-out design with internal ribs to flexibly conform to the objects it grasps, thereby reducing the contact force exerted on the object. This gripper is ideal for objects with difficult geometries or fragile components (e.g., fruit) as it reduces the control precision required to safely manipulate objects. 

## Printing Instructions
The demo compliant gripper was printed with a Bambu Lab printer using a flexible thermoplastic polyurethane (TPU) filament with Shore hardness of 95A. Printer settings included 20% and support generation. The supports were manually removed with flush cutters after printing concluded. 

Not all printers are capable of printing with flexible filaments like TPU. Some printers may require modifications like upgraded printer heads. Printing with TPU may result in longer print times and often requires additional post-processing due to the difficulties in removing the support material. 

## Installation Instructions (SO-101)
No modifications to the robot assembly process or installation are required with the compliant gripper. The external geometry is identical to the original gripper, outside of the removal of some holes and the addition of the cavities/ ribs.

Simply print [Compliant_Moving_Jaw_SO101.stl](stl/Compliant_Moving_Jaw_SO101.stl) and [Compliant_Wrist_Roll_Follower_SO101.stl](stl/Compliant_Wrist_Roll_Follower_SO101.stl) using TPU 95A and install as normal. 

## Further details
This design was created during the June 2025 Hugging Face LeRobot Hackathon by Zach Tabor and Caitlin Freeman from Memphis, TN. The design is loosely inspired from a common compliant gripper design that relies on the Fin Ray Effect&reg;, a concept that was popularized by Festo and used in their compliant grippers.

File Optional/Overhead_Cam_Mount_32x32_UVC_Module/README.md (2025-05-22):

# Overhead Camera (32x32 Camera Module) Installation Guide for SO-100/101
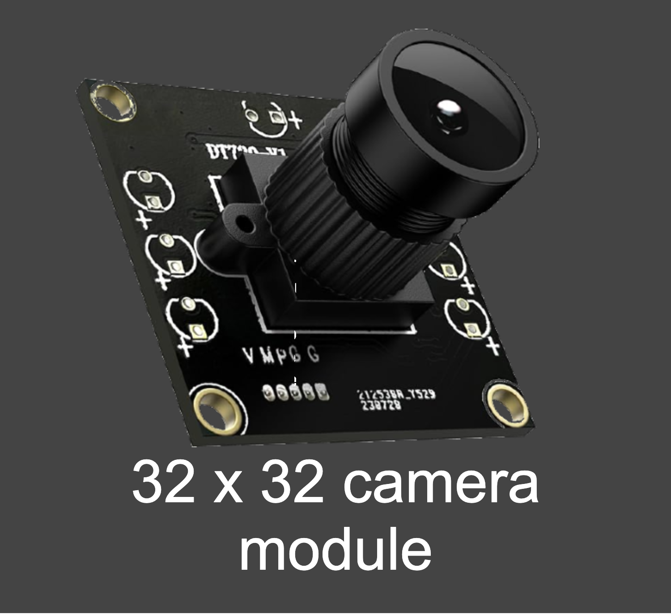
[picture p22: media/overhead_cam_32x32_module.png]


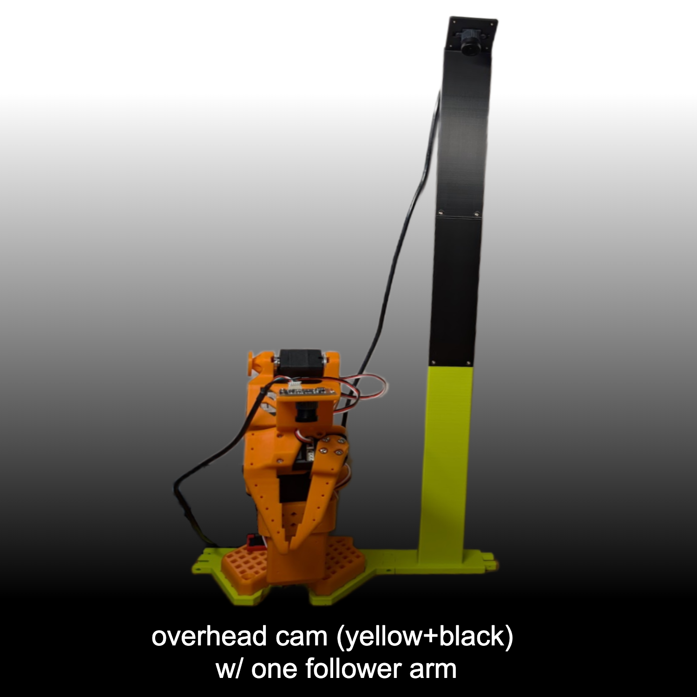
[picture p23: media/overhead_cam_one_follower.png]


## Overview
This guide provides step-by-step instructions for installing an **Overhead Camera** on the SO-100/101 robot using a **32x32 Camera Module** and a 3D-printed **Arm Base** and **Camera Mount**.

## Related Designs
* [Overhead Camera w/ Webcam Installation Guide](../Overhead_Cam_Mount_Webcam/README.md)

## Design Goals

1. Ensure consistent data across SO-100 arm users through standardized camera positioning and arm spacing (for bi-manual case).
2. Provide an overhead view of entire manipulation space.
3. Support both single follower arm and double follower ("bi-manual") arm setups.

## Required Components
- **Camera Module** (1) - A 32mm x 32mm camera module. This is the [tested / recommended model](https://www.amazon.com/dp/B0CLRJZG8D), but many types are available.
- **3D-printed parts**
    - [Arm Base](stl/arm_base.stl) (1 per follower arm)
    - [Camera Mount Bottom](stl/cam_mount_bottom.stl) (1)
    - [Camera Mount Middle](stl/cam_mount_middle.stl) (1)
    - [Camera Mount Top](stl/cam_mount_top.stl) (1)
- **M2 Screws** (16) - these are the smaller screws that came with your Feetech servos.

Screenshot 2025-03-04 at 7 43 33 PM

## Assembly Instructions

### Step 1: Attach the **Camera Module** onto the **Mount Top**

1. Push the **Camera Module** lens through the hole in **Camera Mount Top**.
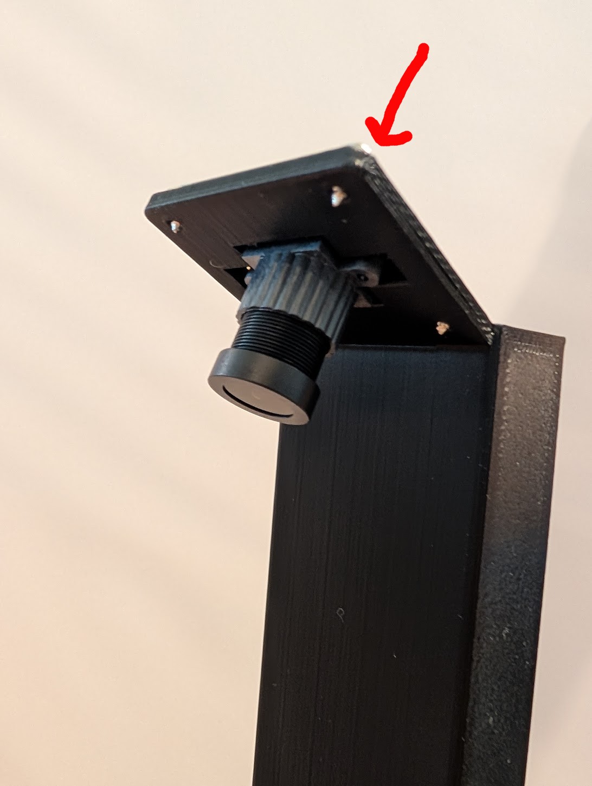
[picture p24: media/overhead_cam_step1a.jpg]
</br> 

2. Use 4 screws to secure the **Camera Module** to the **Mount Top**.
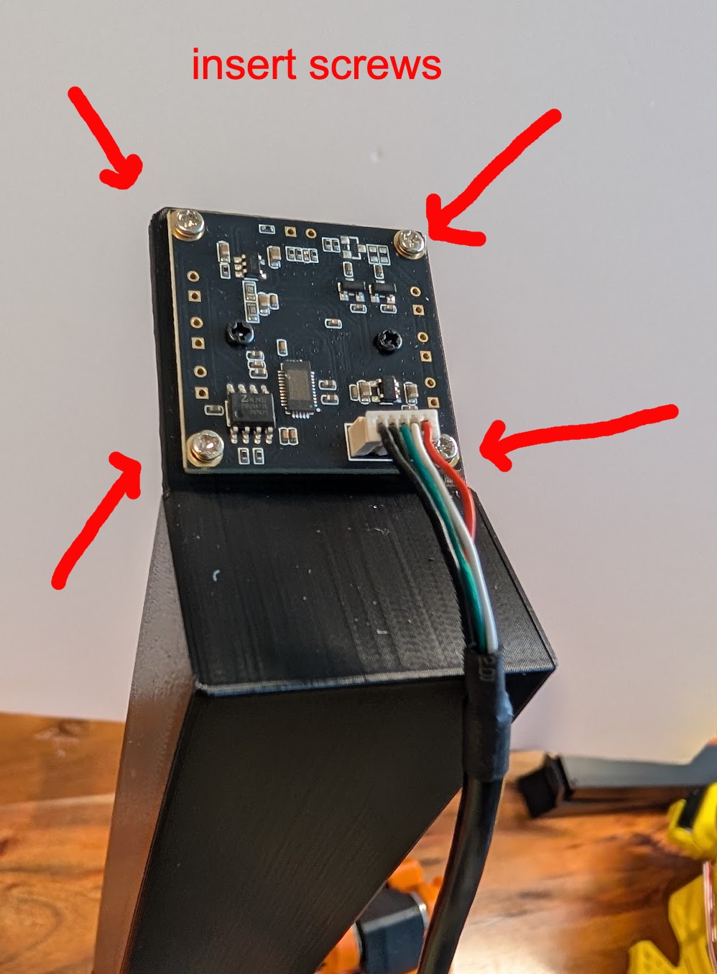
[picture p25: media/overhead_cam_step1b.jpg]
</br> 

### Step 2: Attach the **Mount Middle** to the **Mount Top**.

1. Push the **Mount Middle** into the **Mount Top**.
2. Secure with 4 screws.
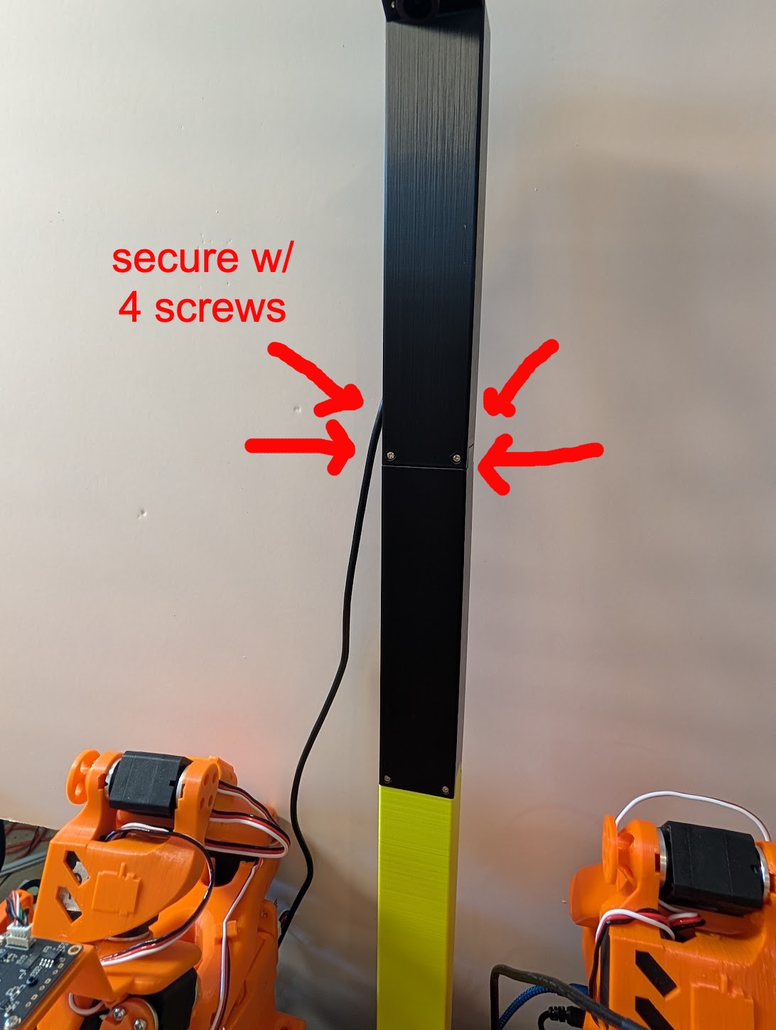
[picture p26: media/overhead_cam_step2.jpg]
</br>

### Step 3: Attach the **Mount Bottom** to the **Mount Middle**.

1. Push the **Mount Bottom** into the **Mount Middle**.
2. Secure with 4 screws.
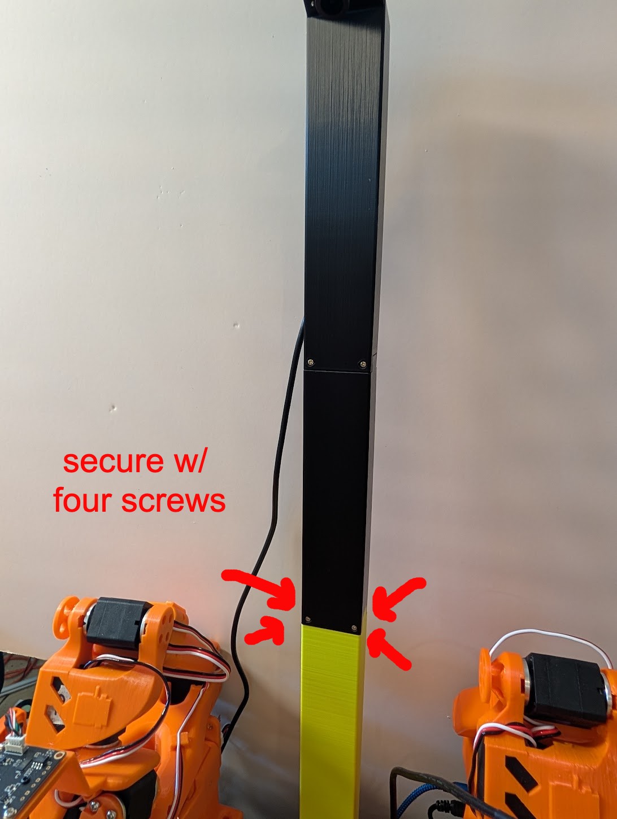
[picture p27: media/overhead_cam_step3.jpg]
</br>

### Step 4: Attach the **Arm Base** to the **Mount Bottom**.
</br>
1. Push the **Arm Base** into the joint lines on the side of the **Mount Bottom**.  (Repeat if you have 2 follower arms.)
### Step 5: Attach the **Follower arm** to the **Arm Base**.
</br>
1. Align the bottom of the **Follower arm** with the top of the **Arm Base**. (Repeat if you have 2 follower arms.)
2. If you use clamps to hold down your **Follower arm**, clamp in the same way you've done before, and it will hold down the camera mount.
   
### Step 6: Configure Software 
1. In your software, add your overhead cam, including setting its resolution and FPS. 
- **Common Settings**:
    - FPS: 30
    - Resolution: 640 x 480, or 1280 x 720 if your workspace is wider.  
2. Look at the video feed from your newly installed camera (On Mac, you can also use *QuickTime*->*New Movie Recording* to see this feed).  You should be able to see the workspace of the arm(s).  Set the screen resolution wider if you need to see more of the workspace.

Screenshot 2025-04-12 at 4 48 35 PM
Screenshot 2025-04-12 at 4 52 09 PM</br>

### Step 7: (Optional) Add Gripper Cameras
</br>
1. For optimal training data, add [**Gripper Cameras**](../Wrist_Cam_Mount_32x32_UVC_Module) designed specifically alongside this camera mount setup.

## Acknowledgements

- Conor McGartoll
- Philip Fung

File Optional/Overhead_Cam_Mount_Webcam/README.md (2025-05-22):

# Overhead Camera (Webcam) Installation Guide for SO-100/101
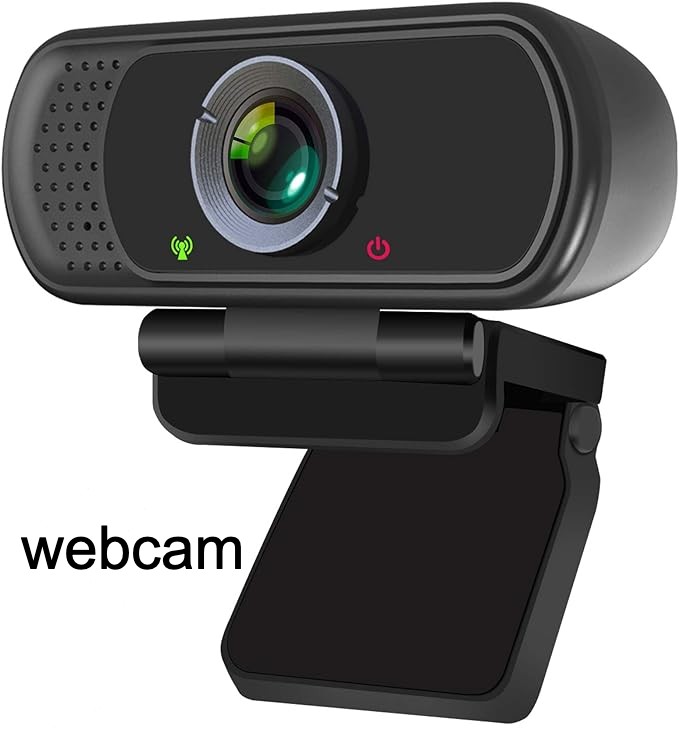
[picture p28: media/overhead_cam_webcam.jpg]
Screenshot 2025-04-12 at 2 52 49 PM

Screenshot 2025-04-12 at 2 52 49 PM
Screenshot 2025-04-12 at 2 53 09 PM
Screenshot 2025-04-12 at 2 47 38 PM

## Overview
This guide provides step-by-step instructions for installing an **Overhead Camera** on the SO-100 robot using a **Web Camera** and a 3D-printed **Arm Base** and **Camera Mount**.

## Related Designs
* [Overhead Camera w/ 32x32 Camera Module](../Overhead_Cam_Mount_32x32_UVC_Module/README.md)

## Design Goals

1. Ensure consistent data across SO-100 arm users through standardized camera positioning and arm spacing (bi-manual).
2. Provide overhead view of entire manipulation space.
3. Support both single follower arm and double follower ("bi-manual") arm setups.

## Required Components
- **Web Camera** (1) - this is the [recommended model](https://www.amazon.com/dp/B082X91MPP).
- **3D-printed parts**
    - [Arm Base](stl/arm_base.stl) (1 per follower arm)
    - [Camera Mount Bottom](stl/cam_mount_bottom.stl) (1)
    - [Camera Mount Top](stl/cam_mount_top.stl) (1)
- **M2 Screws** (8) - these are the smaller screws that came with your Feetech servos.

Screenshot 2025-03-04 at 7 43 33 PM

## Assembly Instructions
### Step 1: Remove the existing base from the **Webcam**
 </br>
Take the **Webcam** out of its package, and: 
1. Remove the soft plastic cover from the joint.
2. Unscrew/remove the screw in the joint.
3. Remove the base from the camera module.

### Step 2: Attach the **Webcam** onto the **Camera Mount Top**
 </br>

1. Push the **Webcam** into the **Camera Mount Top** by aligning the round joint holes.
2. Place the hex bolt into the hexagon shaped-hole and screw **M2 screw** into the opposite hole of the **Camera Mount Top** round joint.
### Step 3: Attach the **Camera Mount Top** to the **Camera Mount Bottom**.


1. Push the **Camera Mount Top** into the **Camera Mount Bottom** by aligning the linear joint lines on the bottom of **Camera Mount Top** with the top of the **Camera Mount Bottom**.
2. Screw an **M2 screw** into each of the 4 holes in the linear joint.
### Step 4: Attach the **Arm Base** to the **Camera Mount Bottom**.
</br>
1. Push the **Arm Base** into the joint lines on the side of the **Camera Mount Bottom**.  (Repeat if you have 2 follower arms.)
### Step 5: Attach the **SO-100 follower arm** to the **Arm Base**.
</br>
1. Align the bottom of the **SO-100 follower arm** with the top of the **Arm Base**. (Repeat if you have 2 follower arms.)
2. If you use clamps to hold down your **SO-100 follower arm**, clamp in the same way you've done before, and it will hold down the camera mount.
   
### Step 6: Configure Software 
1. In your software, add your overhead cam, including setting its resolution and FPS. 
- **Note**: You will likely want to set your resolution to *640 x 480* and FPS to *30* even if the camera module's max resolution/frame rate is higher or wider, as most models work with lower resolutions and any higher will just be data bloat.  This camera mount was specifically designed for 640 x 480 resolution and width.
2. Look at the video feed from your newly installed camera (On Mac, you can also use *QuickTime*->*New Movie Recording* to see this feed).  You should be able to see the workspace of the arm(s).

Screenshot 2025-04-12 at 4 48 35 PM
Screenshot 2025-04-12 at 4 52 09 PM</br>

### Step 7: (Optional) Add Gripper Cameras
</br>
1. For optimal training data, add [**Gripper Cameras**](../Wrist_Cam_Mount_32x32_UVC_Module) designed specifically alongside this camera mount setup.

## Acknowledgements

- Conor Mc Gartoll
    - Design and R & D
- Philip Fung
    - R & D

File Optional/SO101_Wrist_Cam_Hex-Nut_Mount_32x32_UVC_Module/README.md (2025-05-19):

# Hex-Nut Recess Wrist Camera (MF) Installation Guide for SO-101




## Overview
This guide provides step-by-step instructions for installing a **Wrist Camera** (alternate "McGartoll-Fung" design) on the SO-101 robot using a **Camera Module** and a 3D-printed **Hex-Nut Recess Camera Adapter**.

This adapts the [Wrist Camera (MF) UVC Module](../Wrist_Cam_Mount_32x32_UVC_Module/) and [Wrist Camera (MF) UVC Plug‑on Module](../Wrist_Cam_Mount_32x32_UVC_Module/).

## Comparison to Main Design
#### Advantages:
- adapted to use the hex-nut recesses on the wrist of the SO-101 follower arm

#### Disadvantages:
- still requires adaption to the new camera
- requires two screws and two nuts which are not included with the servos
- not backwards-compatible to the SO-100

## Required Components
### Hardware:
- **USB Camera Module** (1) - this is the [recommended model](https://www.amazon.com/innomaker-Computer-Raspberry-Support-Windows/dp/B0CNCSFQC1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), but any 32mm x 32mm USB camera module with min 720p / 30 fps spec will likely work
- [3D-printed Hex-Nut Recess Camera Adapter](stl/SO-ARM101_camera_wrist_mount.stl) (1)
   - I recommend printing it as oriented in the STL using tree supports. 40% infill is recommended to increase sturdiness and avoid wobbling
- **M2 Screws** (4) - these are the smaller screws that came with your Feetech servos.
- **M3 x 8mm Screws** (2)
- **M3 Hex Nuts** (2)

Screenshot 2025-03-04 at 7 43 33 PM

## Assembly Instructions
### Step 1: Attach the Adapter to the Gripper
   
1. 3D print the **Hex-Nut Recess Camera Adapter**.

2. Remove Motor 6, you can leave the [Moving Jaw](../../STL/SO101/Individual/Moving_Jaw_SO101.stl) attached.

3. Insert the hex nuts into the recesses in the [Wrist Roll Element](../../STL/SO101/Individual/Wrist_Roll_Follower_SO101.stl).



4. Reattach Motor 6, secure it with its original M2 screws again.

5. Secure the adapter with the two M3 screws.

### Step 2: Install the Camera
1. Take out the **Camera Module**.
2. Align the 4 holes of the **Camera Module** with the **Camera Adapter**, and attach using 4 **M2 Screws**.



### Step 3: Configure Software and Adjust Focus
1. In your software, set your resolution and FPS. 
- **Note**: You will likely want to set your resolution to *640 x 480* and FPS to *30* even if the camera module's max resolution/frame rate is higher, as most models work with lower resolutions and any higher will just be data bloat.
2. Turn on your arm.  Look at the video feed from your newly installed camera (On Mac, you can also use *QuickTime*->*New Movie Recording* to see this feed).  
- **Note**: The focus on the camera is manual and will look very blurry initially. Adjust the focus by twisting the lens counterclockwise or clockwise until the video feed is clear.

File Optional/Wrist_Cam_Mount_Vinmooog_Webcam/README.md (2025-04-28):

# Wrist Camera Installation Guide for SO100

## Overview
This guide provides step-by-step instructions for installing a **wrist camera** on the SO100 robot using a **cheap webcam** and 3D-printed mounting parts.

## Required Components
### Hardware:
- [Vinmooog Webcam](https://www.amazon.fr/Vinmooog-equipement-Microphone-Enregistrement-conf%C3%A9rences/dp/B0BG1YJWFN/)
- **3D-printed parts:**
  - [Modified wirst](Optional/Wrist_Cam_Mount_Vinmooog_Webcam/stl/Updated_Wrist_Camera_Insert.stl) (Print **1x**), not needed for SO-101
  - [Mount](Optional/Wrist_Cam_Mount_Vinmooog_Webcam/stl/Webcam_Mount_Wrist.stl) (Print **1x**)
- **Fasteners:**
  - 3x **M3 Nut**
  - 1x **M3x12mm bolt**
  - 2x **M3x35mm bolts**

## Assembly Instructions
### Step 1: Print and Prepare the Gripper Mount
1. 3D print the new **SO100 gripper with camera mount**.
2. Insert an **M3 nut** into the dedicated slot in the 3D-printed part.
3. Insert the **motor** into the gripper mount and attach the **gripper mechanism**.

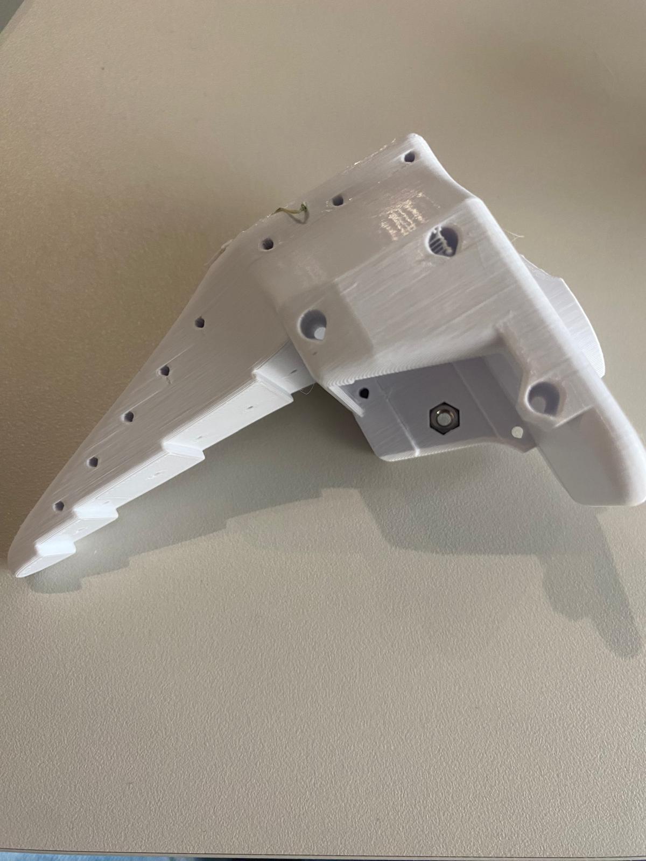
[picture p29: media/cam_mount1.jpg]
    

### Step 2: Attach the Camera Mount
1. Take the **3D-printed camera mount**.
2. Use an **M3x12mm bolt** to secure the camera mount to the **gripper mount**, ensuring that it locks into the previously inserted **M3 nut**.

### Step 3: Install the Camera
1. Insert the **Vinmooog webcam** into the camera mount.
2. Use **two M3x35mm bolts** to secure the camera from the back and insert the nuts in the slots.



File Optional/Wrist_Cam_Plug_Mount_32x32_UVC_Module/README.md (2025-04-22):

# Plug Wrist Camera (MF) Installation Guide for SO-100




## Overview
This guide provides step-by-step instructions for installing a **Wrist Camera** (alternate "McGartoll-Fung" design) on the SO-100 robot using a **Camera Module** and a 3D-printed **Plug-in Camera adapter**.

This an adapatation of [Wrist Camera (MF) UVC Module](../Wrist_Cam_Mount_32x32_UVC_Module/)

## Comparison to Main Design
#### Advantages:
- smaller
- fewer parts
- no additional screws/hardware needed to attach camera
- no removal/replacement of existing pieces
- easy removal/replacement

#### Disdvantages:
- still require to adapt to new camera

## Required Components
### Hardware:
- **USB Camera Module** (1) - this is the [recommended model](https://www.amazon.com/innomaker-Computer-Raspberry-Support-Windows/dp/B0CNCSFQC1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), but any 32mm x 32mm USB camera module with min 720p / 30 fps spec will likely work
- [3D-printed Plugin camera attachment](stl/SO-ARM100_Plug_camera.stl) (1)
   - I recommend printing it as oriented in the STL using tree supports. 40% infill is recommended to increase sturdiness and avoid wobbling
- **M2 Screws** (8) - these are the smaller screws that came with your Feetech servos.

Screenshot 2025-03-04 at 7 43 33 PM

## Assembly Instructions
### Step 1: Plug the new camera module to the Gripper
   
2. 3D print the **Plugin camera attachment**.

3. Attach the **Plugin camera attachment**.
    1. The hole fit into the [Gripper hole](../../STEP/Follower_specific/Moving_Jaw_08d%20v1.step)

4. Secure it with the M2 screws

### Step 2: Install the Camera
1. Take out the **Camera Module**.
2. Align the 4 holes of the **Camera Module** with the **Moving Jaw Replacement**, and attach using 4 **M2 Screws**.



### Step 3: Configure Software and Adjust Focus
1. In your software, set your resolution and FPS. 
- **Note**: You will likely want to set your resolution to *640 x 480* and FPS to *30* even if the camera module's max resolution/frame rate is higher, as most models work with lower resolutions and any higher will just be data bloat.
2. Turn on your arm.  Look at the video feed from your newly installed camera (On Mac, you can also use *QuickTime*->*New Movie Recording* to see this feed).  
- **Note**: The focus on the camera is manual and will look very blurry initially. Adjust the focus by twisting the lens counterclockwise or clockwise until the video feed is clear.

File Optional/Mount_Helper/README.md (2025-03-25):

# Helper piece to mount your so100

Inserting the rectangular hollow pieces can be quite difficult.

To make it easier to assemble, we propose this helper piece that will allow you to push with ease.

Here's a short video of how to use it.

<video src="https://github.com/user-attachments/assets/e1095e7a-b974-4ff0-b3d9-2820359dface"></video>

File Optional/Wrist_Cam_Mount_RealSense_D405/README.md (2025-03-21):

# Wrist Camera Mount for Intel® RealSense™ D405

<p float="left">
  
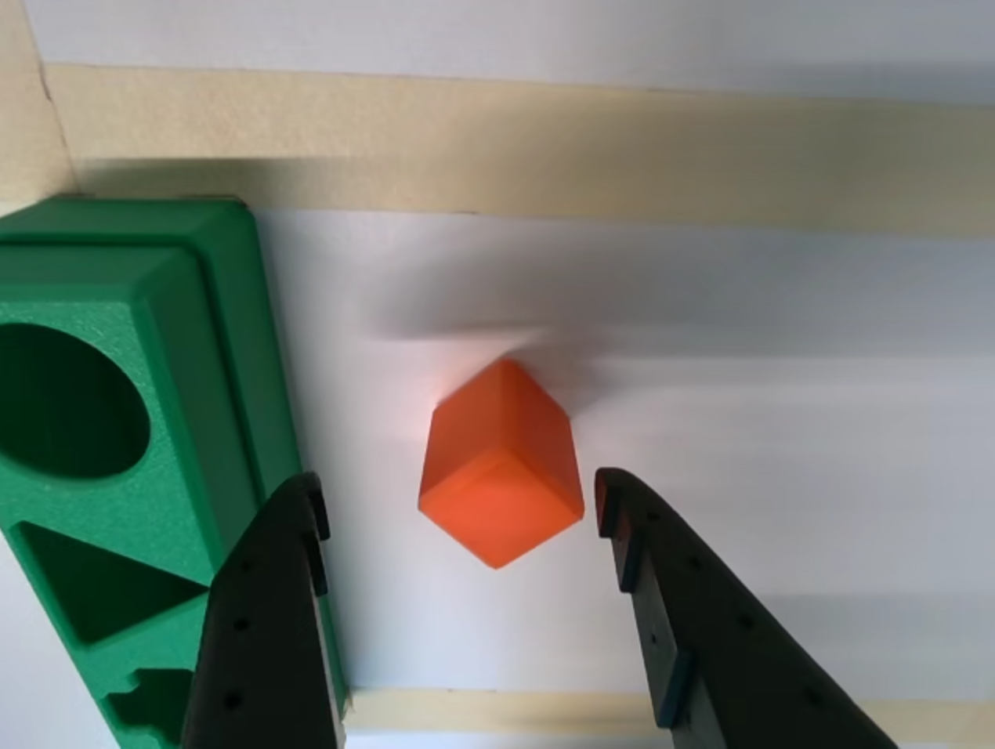
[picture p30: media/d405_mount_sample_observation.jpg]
  
</p>

Use two **DIN 912 M3x6 or M3x8** screws to mount the camera to the wrist.

### Suggested Print Orientation:
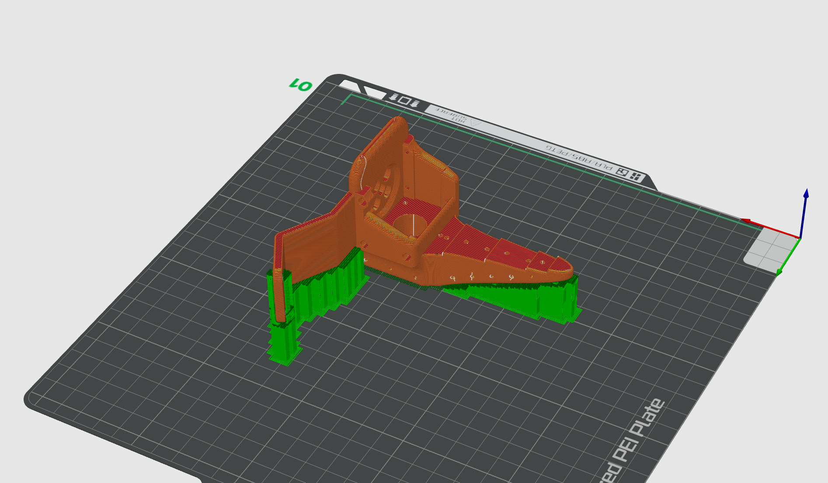
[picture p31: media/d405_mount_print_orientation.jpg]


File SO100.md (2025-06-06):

<div align="center">

   <h1>Standard Open SO-100 Arm</h1>
   <div style="display: flex; gap: 1rem; justify-content: center; align-items: center;" >
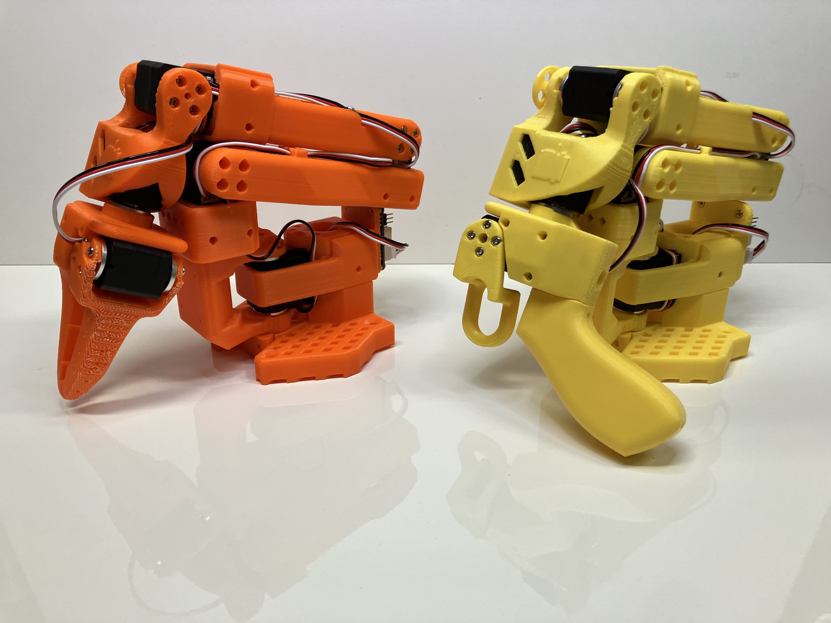
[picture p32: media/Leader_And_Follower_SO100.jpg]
SO-101 follower arm
      
</div>
<br><br>

The SO-100 arm is the original robot arm designed by the [RobotStudio](https://www.therobotstudio.com) in collaboration with [Hugging Face](https://huggingface.co/lerobot).
</div>

## Sourcing Parts

The follower and leader arm for this teleoperation setup will almost the same off the shelf parts. If you plan on creating the classic teleoperation set up to be used with the `LeRobot` library please buy from the Parts for Two Arms below. 

We only have links for US, EU and CN for now. If you find links for other countries, please create an issue or PR so that we add them to the list. Note that prices and items may vary depending on geographic location.

#### Parts For Two Arms (Standard Teleoperation Setup):

| Part | Amount | Unit Cost (US) | Buy US | Unit Cost (EU) | Buy EU | Unit Cost (RMB) | Buy CN |
| --- | --- | --- | --- | --- | --- | --- | --- |
| STS3215 Servo<sup>[1](#myfootnote1)</sup> | 12 | $15 | [Alibaba](https://www.alibaba.com/product-detail/6PCS-7-4V-STS3215-Servos-for_1600523509006.html) | 13€ | [Alibaba](https://www.alibaba.com/product-detail/6PCS-7-4V-STS3215-Servos-for_1600523509006.html) | ￥97.72 | [TaoBao](https://item.taobao.com/item.htm?id=712179366565&skuId=5268252241438)  |
| Motor Control Board | 2 | $11 | [Amazon](https://www.amazon.com/Waveshare-Integrates-Control-Circuit-Supports/dp/B0CTMM4LWK/) | 12€ | [Amazon](https://www.amazon.fr/-/en/dp/B0CJ6TP3TP/) | ￥27 | [TaoBao](https://detail.tmall.com/item.htm?id=738817173460&skuId=5096283384143) |
| USB-C Cable 2 pcs | 1 | $7 | [Amazon](https://www.amazon.com/Charging-etguuds-Charger-Braided-Compatible/dp/B0B8NWLLW2/?th=1) | 7€ | [Amazon](https://www.amazon.fr/dp/B07BNF842T/) | ￥23.9\*2 | [TaoBao](https://detail.tmall.com/item.htm?id=44425281296&skuId=5611379016222)  |
| Power Supply<sup>[2](#myfootnote2)</sup> | 2 | $10 | [Amazon](https://www.amazon.com/Facmogu-Switching-Transformer-Compatible-5-5x2-1mm/dp/B087LY41PV/) | 13€ | [Amazon](https://www.amazon.fr/-/en/dp/B01HRR9GY4/) | ￥22.31 | [TaoBao](https://item.taobao.com/item.htm?id=544824248494&skuId=4974994129990)  |
| Table Clamp 4pcs | 1 | $9 | [Amazon](https://www.amazon.com/TAODAN-Trigger-Ratchet-Woodworking-Processes/dp/B0DJNXF8WH?rps=1&sr=1-18) | ￥9.2 | [TaoBao](https://detail.tmall.com/item.htm?id=801399113134&skuId=5633627126649) |
| Screwdriver Set<sup>[3](#myfootnote3)</sup> | 1 | $6 | [Amazon](https://www.amazon.com/Precision-Phillips-Screwdriver-Electronics-Computer/dp/B0DB227RTH) | 10€ | [Amazon](https://www.amazon.fr/dp/B08ZXVMVYD/) | ￥14.9 | [TaoBao](https://detail.tmall.com/item.htm?id=675684600845&skuId=4856851392176) |
| Total | --- | $232 | --- | 244€ | --- | ￥1343.16 | --- |

#### Parts for One Arm:

| Part | Amount | Unit Cost (US) | Buy US | Unit Cost (EU) | Buy EU | Unit Cost (RMB) | Buy CN |
| --- | --- | --- | --- | --- | --- | --- | --- |
| STS3215 Servo<sup>[1](#myfootnote1)</sup> | 6 | $14 | [Alibaba](https://www.alibaba.com/product-detail/Top-Seller-Low-Cost-Feetech-STS3215_1600999461525.html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) | 13€ | [Alibaba](https://www.alibaba.com/product-detail/Top-Seller-Low-Cost-Feetech-STS3215_1600999461525.html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) | ￥97.72 | [TaoBao](https://item.taobao.com/item.htm?id=712179366565&skuId=5268252241438)  |
| Motor Control Board | 1 | $11 | [Amazon](https://www.amazon.com/Waveshare-Integrates-Control-Circuit-Supports/dp/B0CTMM4LWK/) | 12€ | [Amazon](https://www.amazon.fr/-/en/dp/B0CJ6TP3TP/) | ￥27 | [TaoBao](https://detail.tmall.com/item.htm?id=738817173460&skuId=5096283384143) |
| USB-C Cable 2 pcs | 1 | $7 | [Amazon](https://www.amazon.com/Charging-etguuds-Charger-Braided-Compatible/dp/B0B8NWLLW2/?th=1) | 7€ | [Amazon](https://www.amazon.fr/dp/B07BNF842T/) | ￥23.9 | [TaoBao](https://detail.tmall.com/item.htm?id=44425281296&skuId=5611379016222)  |
| Power Supply<sup>[2](#myfootnote2)</sup> | 1 | $10 | [Amazon](https://www.amazon.com/Facmogu-Switching-Transformer-Compatible-5-5x2-1mm/dp/B087LY41PV/) | 13€ | [Amazon](https://www.amazon.fr/-/en/dp/B01HRR9GY4/) | ￥22.31 | [TaoBao](https://item.taobao.com/item.htm?id=544824248494&skuId=4974994129990)  |
| Table Clamp 2pcs | 1 | $5 | [Amazon](https://www.amazon.com/Mr-Pen-Carpenter-Clamp-6inch/dp/B092L925J4/) | 8€ | [Amazon](https://www.amazon.fr/-/en/dp/B08HZ1QRBF/) | ￥7.8 | [TaoBao](https://detail.tmall.com/item.htm?id=738636473238&skuId=5505939904942) |
| Screwdriver Set<sup>[3](#myfootnote3)</sup> | 1 | $6 | [Amazon](https://www.amazon.com/Precision-Phillips-Screwdriver-Electronics-Computer/dp/B0DB227RTH) | 10€ | [Amazon](https://www.amazon.fr/dp/B08ZXVMVYD/) | ￥14.9 | [TaoBao](https://detail.tmall.com/item.htm?id=675684600845&skuId=4856851392176) |
| Total | --- | $123 | --- | 128€ | --- | ￥682.23 | --- |

## Printing the Parts

A variety of 3D printers are acceptable to print the parts necessary of the follower and leader arm. Follow the steps below to ensure a good print.

1. Choose a printer: The STL files provided ready to print on many FDM printers. Below are the tested and suggested settings though others may work.
   1. Material: PLA
   2. Nozzle Diameter and Precision: 0.4mm nozzle diameter at 0.2mm layer height or 0.6mm nozzle at 0.4mm layer height.
   3. Infill Density: 13%
   4. Sample Printers: [Prusa MINI+](https://www.prusa3d.com/product/original-prusa-mini-semi-assembled-3d-printer-4/), [UP Plus 2](https://shop.tiertime.com/product/tiertime-up-plus-2-3d-printer/), [Creality Ender 3](https://www.amazon.com/Comgrow-Creality-Ender-Aluminum-220x220x250mm/dp/B07BR3F9N6/), [Bambu Lab A/P/X-series](https://bambulab.com)
2. Set up the printer
   1. Setup and Takedown
      1. Ensure that the printer is calibrated and the bed level is correctly set using the printer specific instructions.
      2. Clean the print bed, making sure it is free from dust, or grease. If cleaning the bed using water, or other liquid, dry the bed.
      3. If your printer recommends it, use a standard glue stick and apply a thin, even layer of glue across the print area of the bed. Avoid clumping or uneven application.
      4. Load the printer filament using printer specific instructions.
      5. Ensure the printer settings match the ones suggested above (most printers have multiple settings so choose the ones that most closely match).
      6. Set for supports everywhere but ignore slopes greater than 45 degrees to the horizontal.
      7. There should be no supports in the screw holes with horizontal axes.
3. Check Printer Accuracy
   1. In the [Gauges](/stl_files_for_3dprinting/Gauges) folder, there are two types of gauges, one to check the size of print against a standard 4x2 lego block and one against a STS3215 servo.
      1. If you have a STS3215 servo, print:
         1. [Gauge Zero](/stl_files_for_3dprinting/Gauges/Gauge_0.STL)
         2. [Gauge Tight](/stl_files_for_3dprinting/Gauges/Gauge_tight_1.STL)
      2. If you have a standard lego block, print:
         1. [Gauge Zero](/stl_files_for_3dprinting/Gauges/Lego_Size_Test_02_zero.STL)
         2. [Gauge -0.1](/stl_files_for_3dprinting/Gauges/Lego_Size_Test_02_minuspoint1.STL)
   2. Test the gauge 0 against your given object (Lego or Servo). The fit should be similar to this [tutorial](https://youtu.be/dss8E3DG2rA).
   3. If the fit is appropriate, go onto Step 4, otherwise, change your printer settings and try again or create an issue.
4. Print the parts: All the parts for the leader or follower are contained in a single file, correctly orientated for z upwards to minimize supports.

   1. For printer bed sizes of 220mmx220mm (such as the Ender), print these files:
      1. [Follower](/stl_files_for_3dprinting/Follower/Print_Follower_SO_ARM100_08k_Ender.STL)
      2. [Leader](/stl_files_for_3dprinting/Leader/Print_Leader_SO_ARM100_08k_Ender.STL)
   2. For printer bed sizes of 205mm x 250mm (such as the Prusa/Up):
      1. [Follower](/stl_files_for_3dprinting/Follower/Print_Follower_SO_ARM100_08k_UP_Prusa.STL)
      2. [Leader](/stl_files_for_3dprinting/Leader/Print_Leader_SO_ARM100_08k_UP_Prusa.STL)
   3. For Bambu Lab A-series:
      1. Follower ([Part 1](/stl_files_for_3dprinting/Follower/Print_Follower_SO_ARM100_08k_UP_BambuLabA1Mini_part1.STL)) ([Part 2](/stl_files_for_3dprinting/Follower/Print_Follower_SO_ARM100_08k_UP_BambuLabA1Mini_part2.STL))
      2. Leader ([Part 1](/stl_files_for_3dprinting/Leader/Print_Leader_SO_ARM100_08k_UP_BambuLabA1Mini_part1.stl)) ([Part 2](/stl_files_for_3dprinting/Leader/Print_Leader_SO_ARM100_08k_UP_BambuLabA1Mini_part2.stl))
   4. For Bambu Lab P-series & X-series
      1. [Follower](/stl_files_for_3dprinting/Follower/Print_Follower_Bambu_P1P.3mf)
      2. [Leader](/stl_files_for_3dprinting/Leader/Print_Leader_Bambu_P1P.3mf)

5. Take Down
   1. After the print is done, use a putty knife to scrape the parts off the print bed.
   2. Remove any support material from parts.

### Don't Own a 3D printer?
Go here: [Printing services](./3DPRINT.md)

## Assembly tutorial, data collection and AI training

Follow the [complete guide of LeRobot](https://huggingface.co/docs/lerobot/so100).

It points to [our video tutorial](https://www.youtube.com/watch?v=FioA2oeFZ5I&ab_channel=HuggingFace).
Note: we removed to auto-calibration at the end in favor of manual calibration which is more robust.

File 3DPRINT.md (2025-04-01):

# 3D Printing Services

There are different ways to get your parts 3D printed, below are the options and which one to choose. We will add more services once we verify them. If you tried another service please let us know so we can add it here. Additionaly SeeedStudio also sells the 3D printed parts only: [SO-ARM100 3D-Printed Enclosure](https://www.seeedstudio.com/SO-ARM100-3D-printed-Enclosure-p-6409.html).  

- [Europe](#craftcloud3d) (Craftcloud3d) :fr: :de: :uk: :it: :es:
- [US](#craftcloud3d) (Craftcloud3d) :us:
- [China](#pcbway) (PCBWay) :cn:

### [Craftcloud3d](https://craftcloud3d.com)
**PCBWay** ships worldwide and has partners in different countries that produce the parts. This makes it flexible, although pricing can vary.

To get your parts made you can go to [craftcloud3d.com](https://craftcloud3d.com/upload) and upload all files inside these two folders (25 files in total): `stl_files_for_3dprinting/Individual/Follower` and `stl_files_for_3dprinting/Individual/Leader` here:

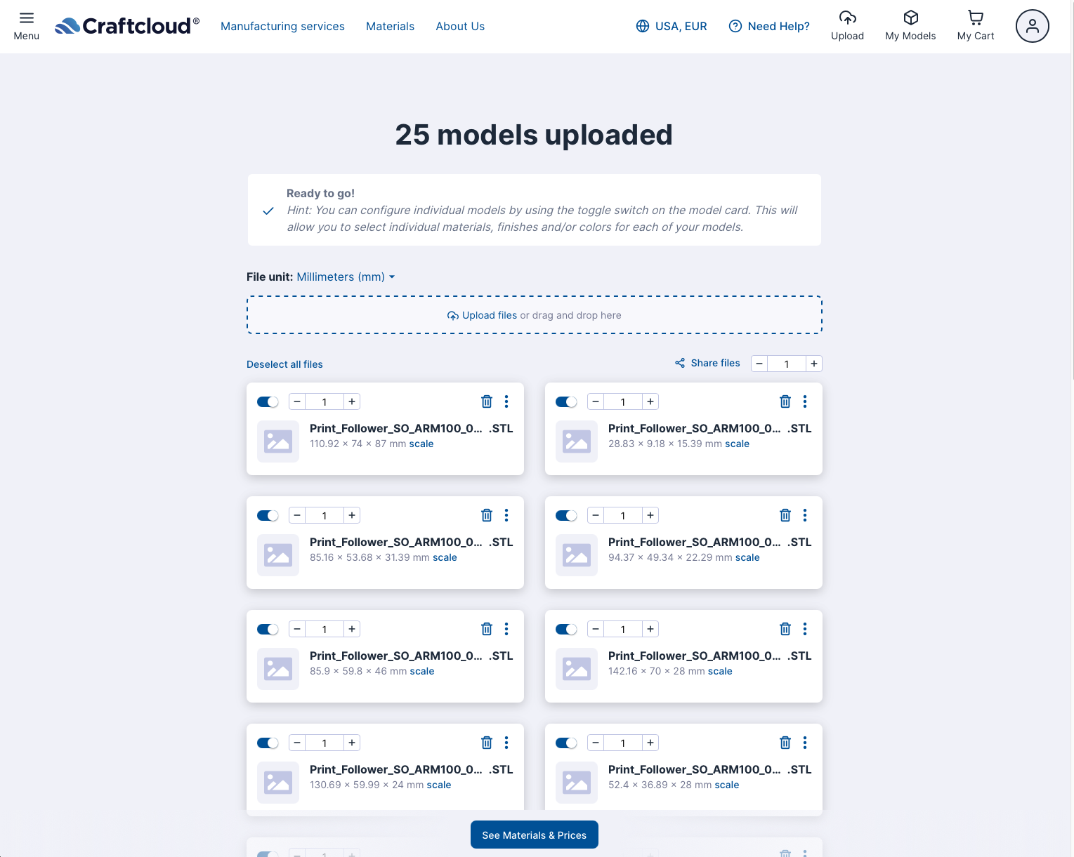
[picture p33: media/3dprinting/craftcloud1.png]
Craftcloud3d


Then click `See Materials & Pricing` button, and on the next page select the material. In our case `PLA+`.

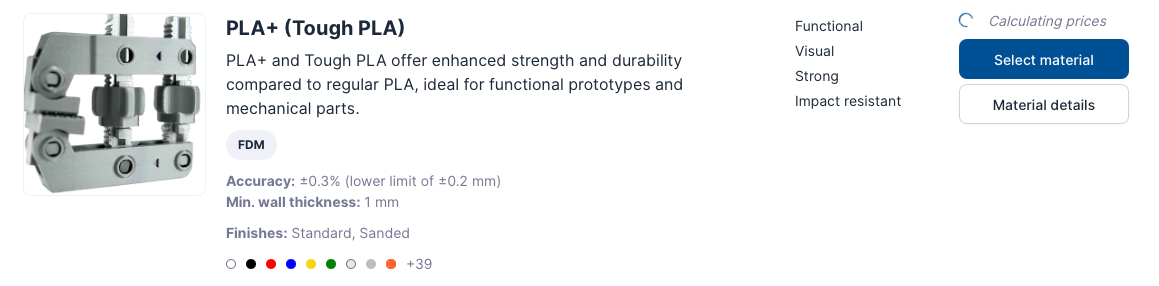
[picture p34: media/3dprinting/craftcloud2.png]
Craftcloud3d


Click `Select Material` button and you then have to select the finish. Here choose:
- `Finish` = Standard 
- `Infill` = 20% (If you don't see the infill options, wait until the price is calculated)

And click `Select Finish` to move to the next page.

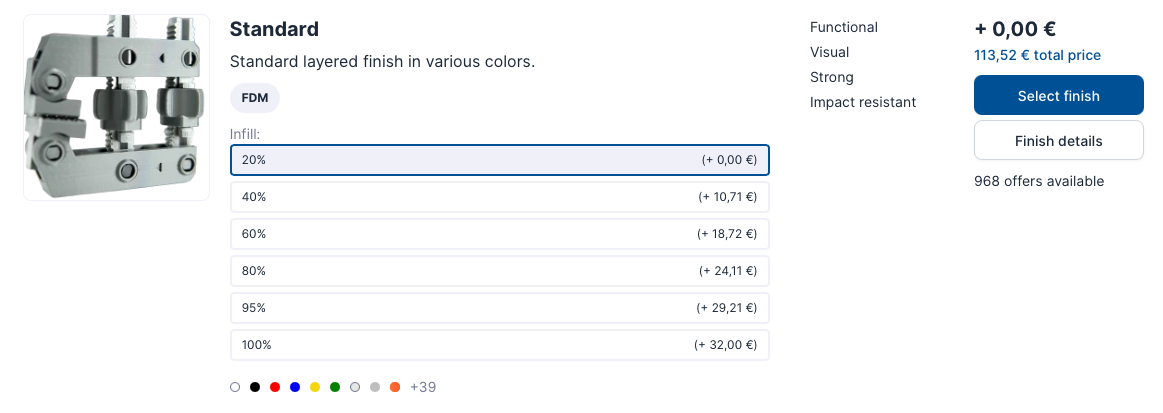
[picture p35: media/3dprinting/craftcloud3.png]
Craftcloud3d


Next choose the color, and click `See offers`.

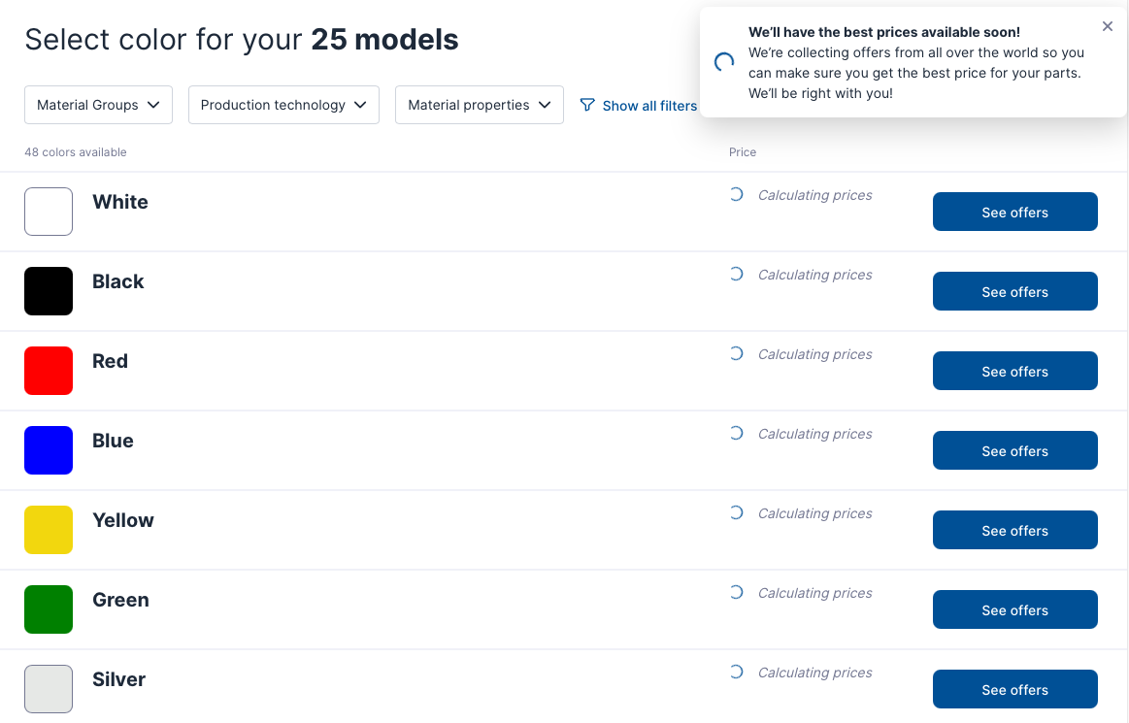
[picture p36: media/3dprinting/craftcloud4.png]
Craftcloud3d


Finally choose your manufacturer. You can choose manufacturer based on price, delivery date and production location.

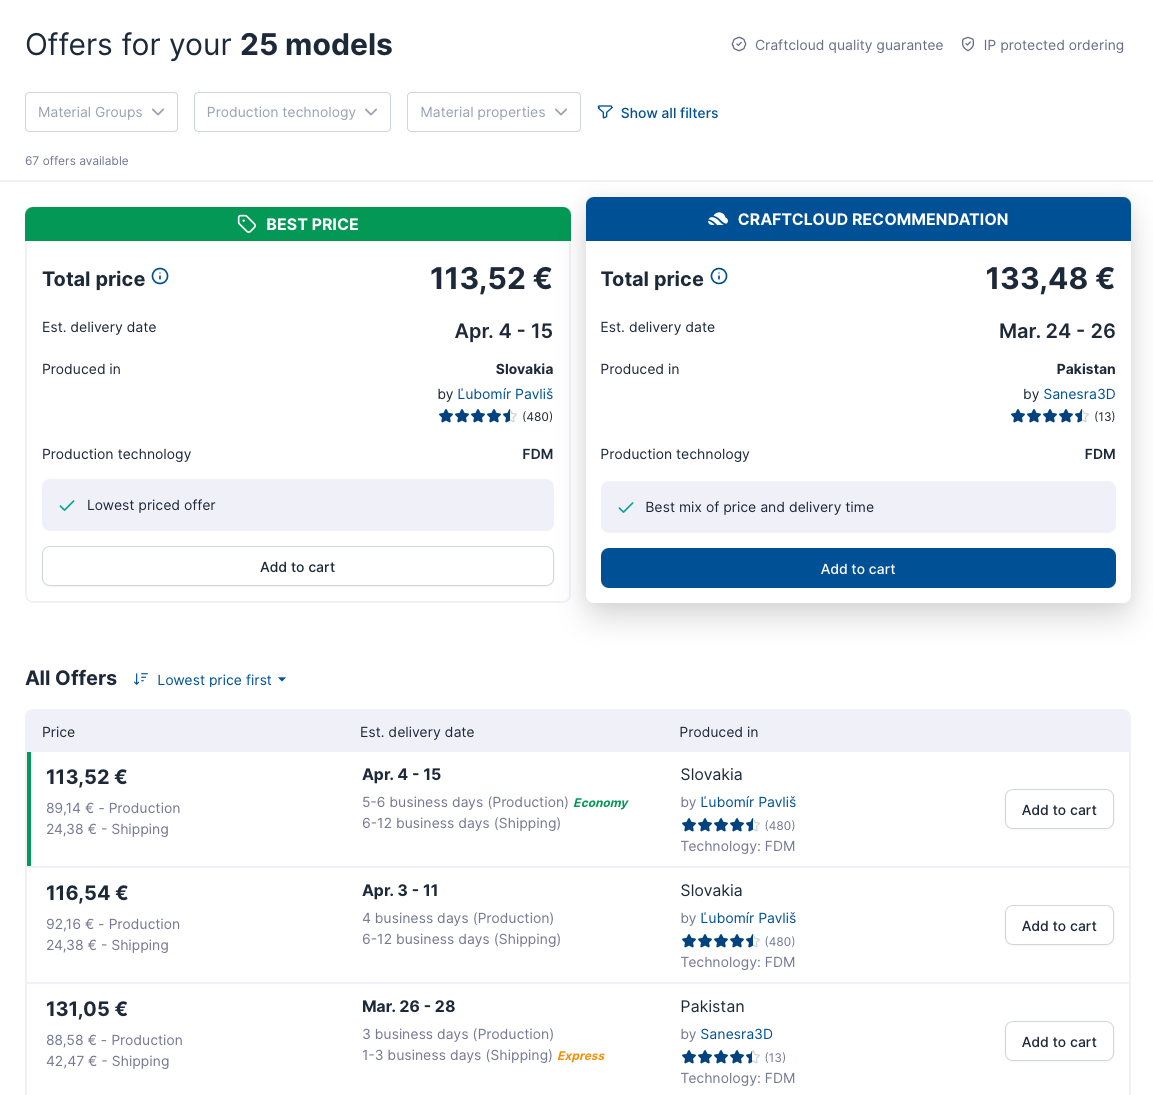
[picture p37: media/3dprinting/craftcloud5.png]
Craftcloud3d


And thats it, once the parts arrive you are ready to assemble your SO100!

### [PCBWay](pcbway.com)
**PCBWay** ships worldwide but outside of China import taxes should be paid. This makes it more expensive to order here.

To get your parts made you can go to [pcbway.com](https://www.pcbway.com/rapid-prototyping/manufacture/?type=2) and upload these two files `stl_files_for_3dprinting/Leader/Print_Leader_SO_ARM100_08k_Ender.STL` and `stl_files_for_3dprinting/Follower/Print_Follower_SO_ARM100_08k_Ender.STL` here:

PCBWay

Then select the following settings:
- `Quantity` = 1 for both (Or more if you need more).
- `Design Units` = mm
- `Material` -> Custom material -> and type `PLA+`
- `Product Desc` -> DIY Entertainment -> Robot components
- `Other special requests` =  'FDM, 20% infill' (And you can specify the color you want)

This tells PCBWay we want to use [FDM](https://www.hubs.com/knowledge-base/what-is-fdm-3d-printing/) 3D printing process with 20% infill. You don't need to change the rest of the options. And once you verified everything you can click `Submit`.

PCBWay

Now the parts will be verified and you will be given a final quotation with shipping costs. The pricing can vary but our experience was that the total for both a leader and a follower was around ~95,- dollars. You can have contact with PCBWay via their online portal.

PCBWay

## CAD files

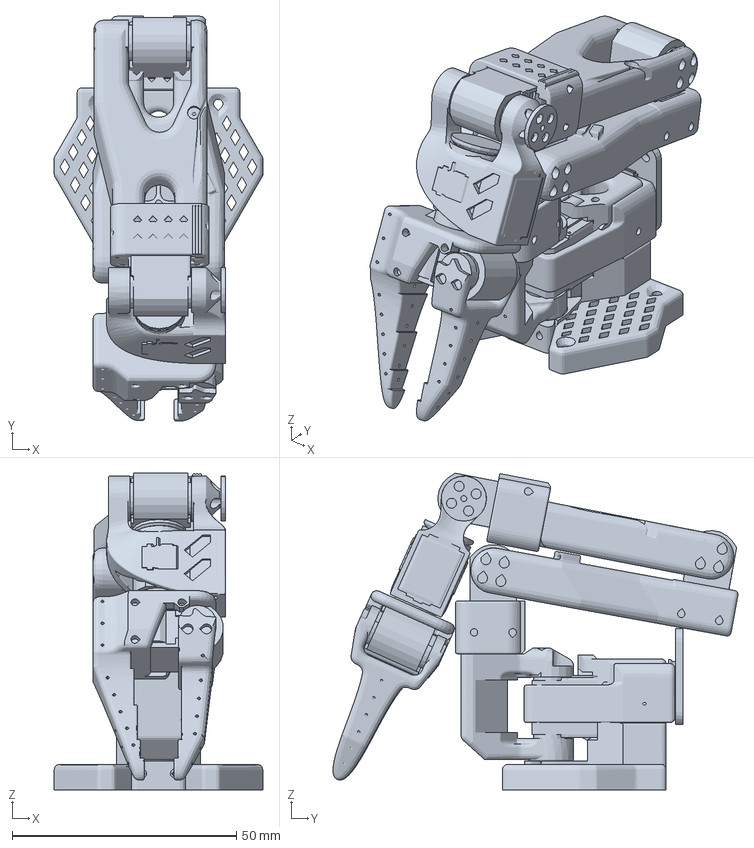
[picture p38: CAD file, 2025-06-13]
Mini/Mini_SO_100_01g.3mf
46.6 x 90.4 x 70.7 mm

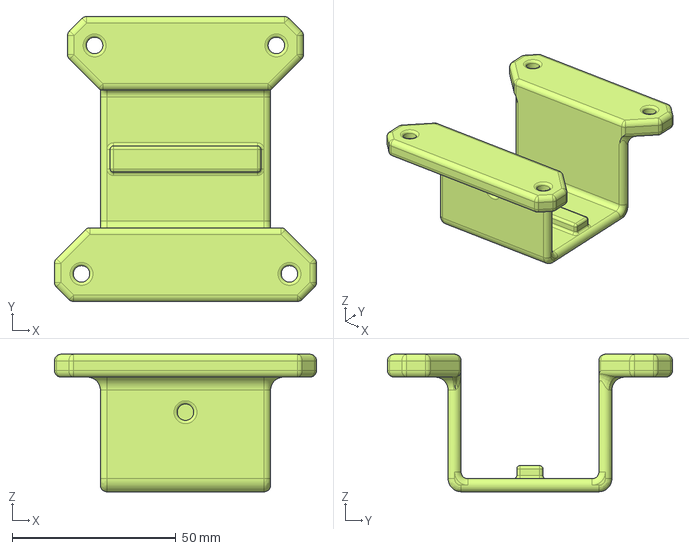
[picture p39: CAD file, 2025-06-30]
Optional/4040_Base_Mount/step/4040_base_mount.step
80.0 x 87.0 x 42.0 mm

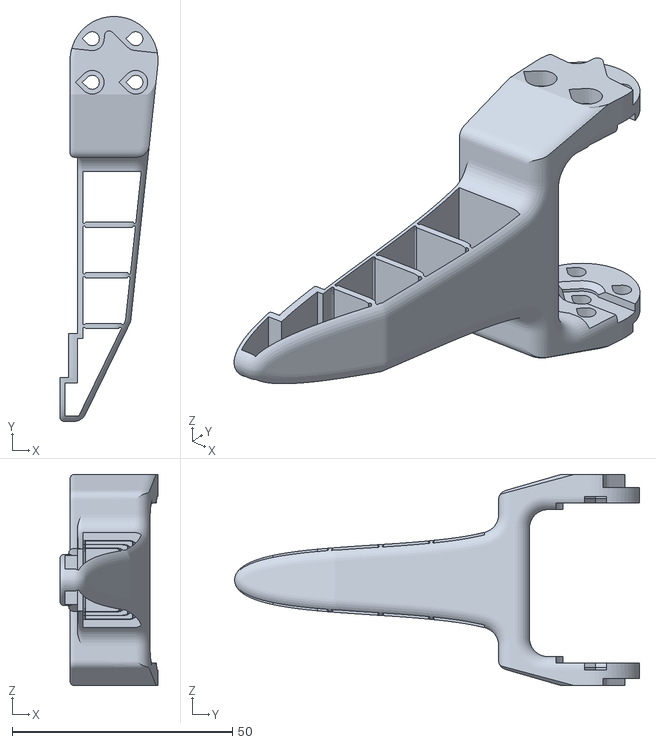
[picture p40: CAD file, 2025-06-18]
Optional/Compliant_Gripper/stl/Compliant_Moving_Jaw_SO101.stl
22.3 x 92.0 x 48.0

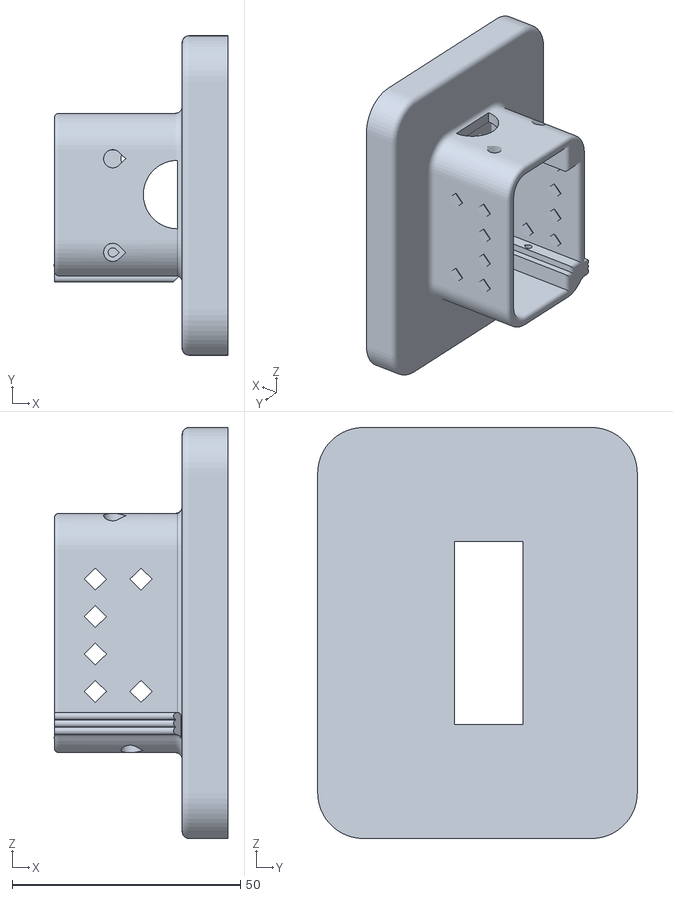
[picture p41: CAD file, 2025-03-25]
Optional/Mount_Helper/stl/mount_helper v2.stl
38.0 x 70.0 x 90.0

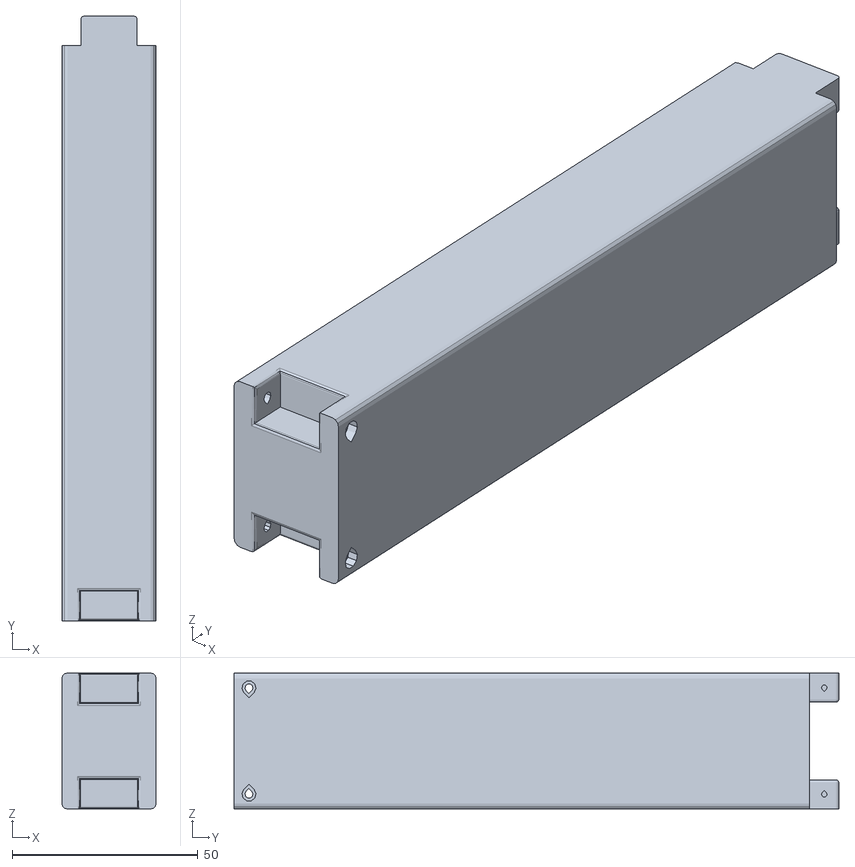
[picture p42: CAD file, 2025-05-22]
Optional/Overhead_Cam_Mount_32x32_UVC_Module/stl/cam_mount_middle.stl
25.4 x 162.9 x 36.6

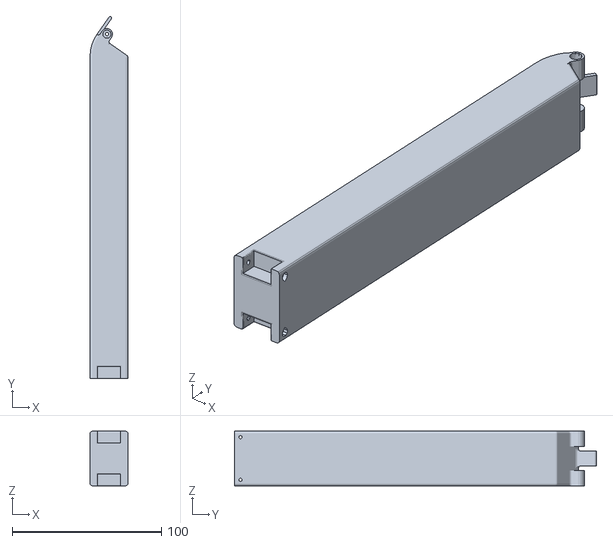
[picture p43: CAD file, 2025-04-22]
Optional/Overhead_Cam_Mount_Webcam/stl/cam_mount_top.stl
25.4 x 242.5 x 36.6

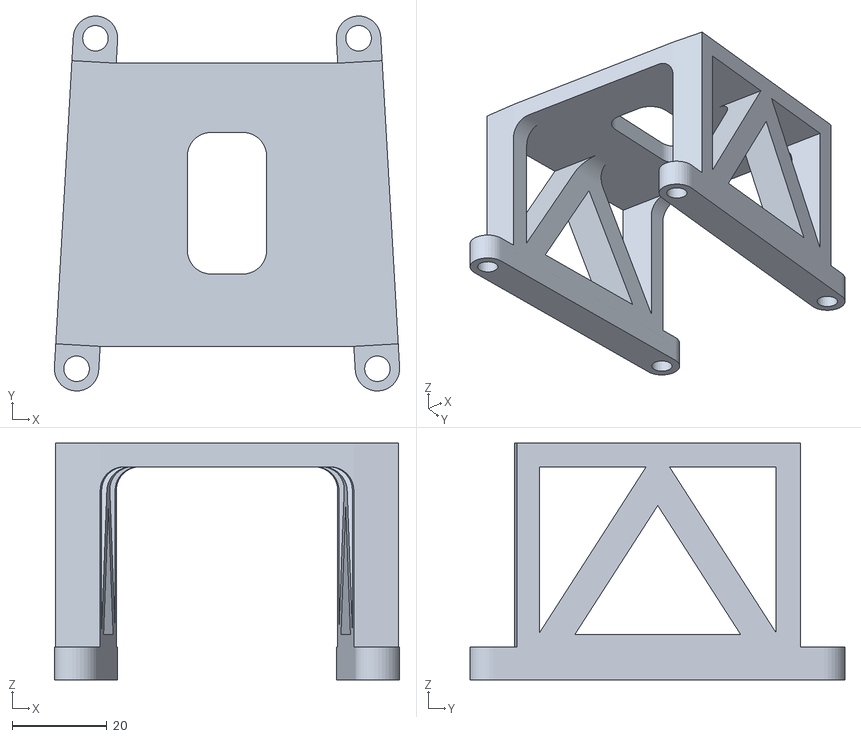
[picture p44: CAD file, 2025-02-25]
Optional/Raised_Base/Raised_Base_Extension.stl
72.9 x 79.2 x 50.0

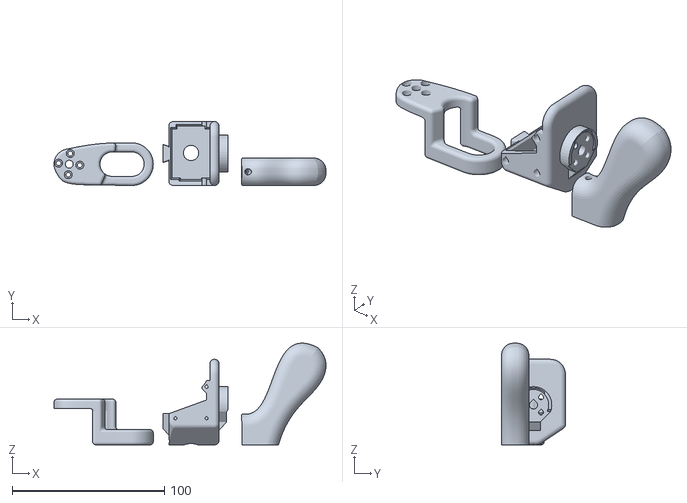
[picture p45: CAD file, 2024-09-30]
Optional/Small_Handle/Small_Leader_Handle.STL
178.5 x 42.0 x 66.8

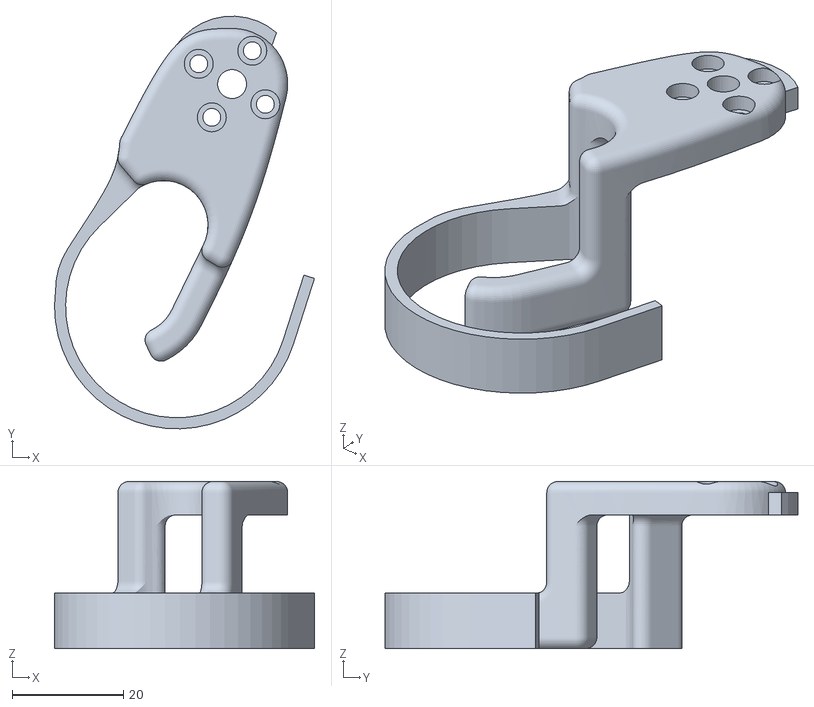
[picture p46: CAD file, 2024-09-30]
Optional/Springy_Trigger/Springy_Trigger.STL
46.7 x 74.1 x 30.0

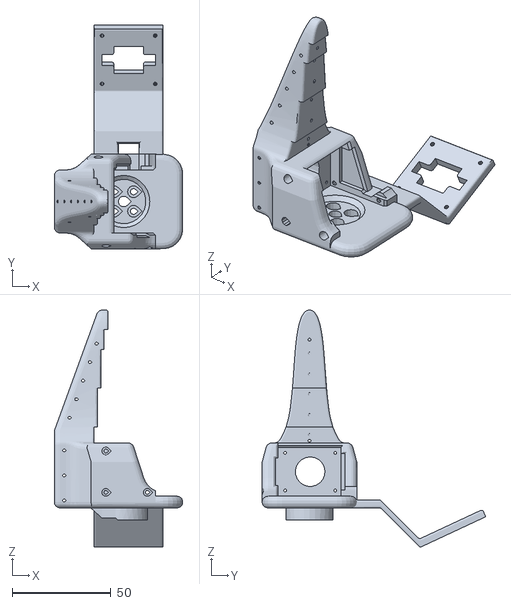
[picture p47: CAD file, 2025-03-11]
Optional/Wrist_Cam_Mount_32x32_UVC_Module/stl/Wrist_Cam_Mount_32x32_UVC_Module_SO100.stl
65.1 x 113.4 x 120.2

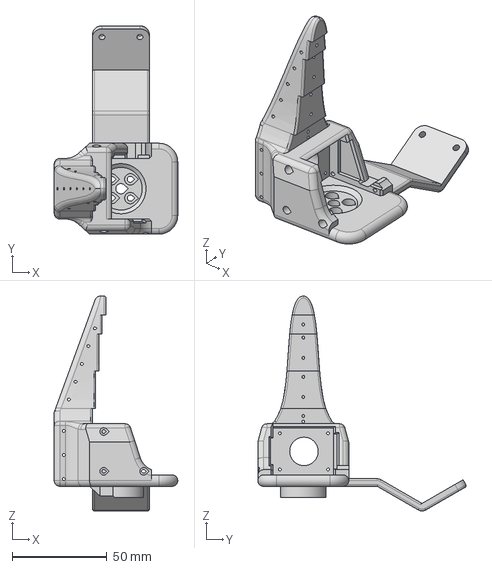
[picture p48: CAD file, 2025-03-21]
Optional/Wrist_Cam_Mount_RealSense_D405/Wrist_Roll_D405_Holder.step
65.2 x 109.9 x 113.4 mm

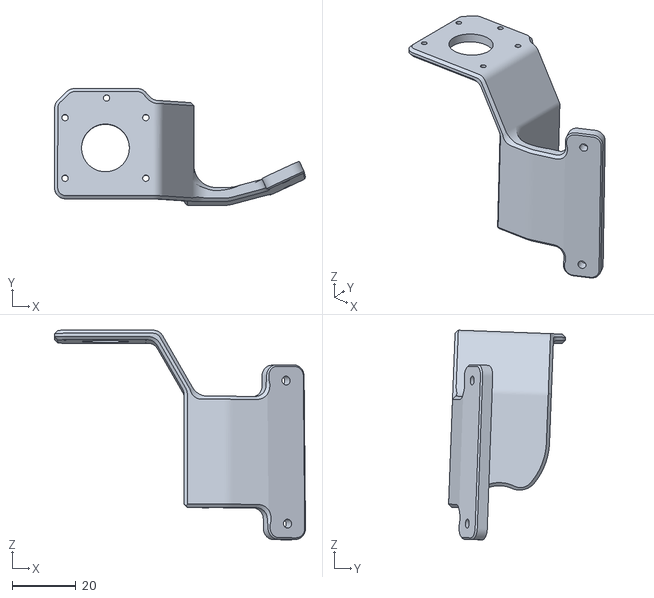
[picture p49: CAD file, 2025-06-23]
Optional/Wrist_Cam_Mount_RealSense_D435/stl/Wrist_cam_mount_RealSense_D435.stl
78.9 x 36.8 x 65.9

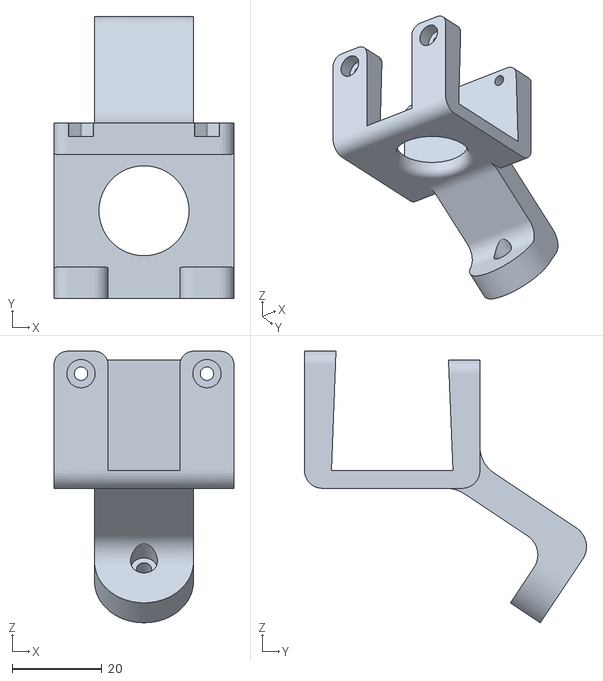
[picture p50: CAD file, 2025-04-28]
Optional/Wrist_Cam_Mount_Vinmooog_Webcam/stl/Webcam_Mount_Wrist.stl
40.0 x 62.7 x 60.4

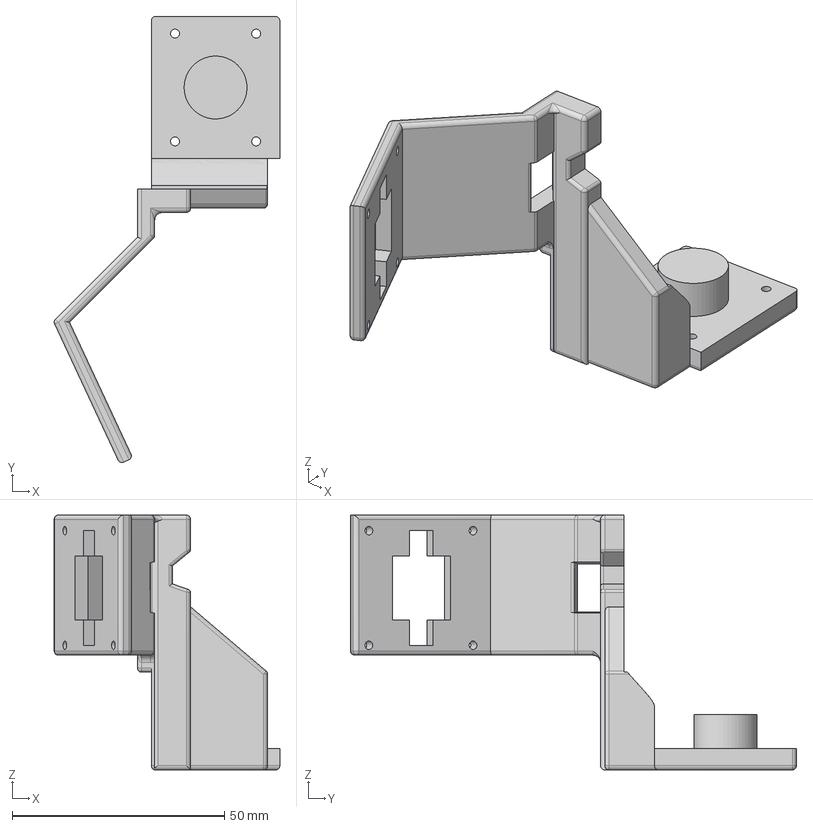
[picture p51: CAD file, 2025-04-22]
Optional/Wrist_Cam_Plug_Mount_32x32_UVC_Module/stl/SO-ARM100 Plug camera.step
53.1 x 104.9 x 60.0 mm

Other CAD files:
Simulation/SO100/assets/Wrist_Pitch_Roll.stl
Simulation/SO101/assets/wrist_roll_follower_so101_v1.stl
STEP/SO100/Follower_Specific/Moving_Jaw_08d v1.step
STEP/SO100/Leader_Specific/Wrist_Roll_05m_Leader_02ba v1.step
Mini/Mini_SO_100_01g.STL
Optional/4040_Base_Mount/stl/4040_base_mount.stl
Optional/Compliant_Gripper/stl/Compliant_Wrist_Roll_Follower_SO101.stl
Optional/Overhead_Cam_Mount_32x32_UVC_Module/stl/arm_base.stl
Optional/Overhead_Cam_Mount_32x32_UVC_Module/stl/cam_mount_bottom.stl
Optional/Overhead_Cam_Mount_32x32_UVC_Module/stl/cam_mount_top.stl
Optional/Overhead_Cam_Mount_Webcam/stl/arm_base.stl
Optional/Overhead_Cam_Mount_Webcam/stl/cam_mount_bottom.stl
Optional/SO101_Wrist_Cam_Hex-Nut_Mount_32x32_UVC_Module/stl/SO-ARM101_camera_wrist_mount.step
Optional/SO101_Wrist_Cam_Hex-Nut_Mount_32x32_UVC_Module/stl/SO-ARM101_camera_wrist_mount.stl
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

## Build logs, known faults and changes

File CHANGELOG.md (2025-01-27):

## [v0.1.13] - 2025-01-27
- Uploaded individual step files in one folder

## [v0.1.12] - 2024-10-01
- Uploaded URDF for early draft of 7DOF SO-Arm to allow modelling to begin.

## [v0.1.11] - 2024-10-01
- Reverted Waveshare mounting design to earlier version.
- Replaced CAD for Solidworks as zip: Version SO_5DOF_ARM100_08k
- Replaced stl files for leader and follower arms: Version SO_5DOF_ARM100_08k

## [v0.1.10] - 2024-09-30
- 2 last bug fixes!
- Replaced CAD for Solidworks as zip: Version SO_5DOF_ARM100_08k
- Replaced stl files for leader and follower arms: Version SO_5DOF_ARM100_08k

## [v0.1.9] - 2024-09-30
- Replaced CAD for Solidworks as zip: Version SO_5DOF_ARM100_08k
- Replaced stl files for leader and follower arms: Version SO_5DOF_ARM100_08k

## [v0.1.8] - 2024-09-30
- Uploaded CAD for Solidworks as zip: Version SO_5DOF_ARM100_08j
- Both follower and leader in a single assembly.
- Uploaded Alternative Leader Controllers with smaller sizes and sprung trigger.

## [v0.1.7] - 2024-09-27
- Added stl files for leader and follower arms: Version SO_5DOF_ARM100_08j
- Ready-to-print trays with max print areas for Ender (218mmx218mm) and Prusa/Up (202.5mm x 247.5mm).

## [v0.1.6] - 2024-09-25
- Added URDF for SO_5DOF_ARM100_8j
- Added link to URDF viewer at bottom of Readme

## [v0.1.5] - 2024-08-06
- Updated read.me with clearer instructions related to the new stl files.

## [v0.1.4] - 2024-08-01
- Deleted previous stl files for the arm
- Uploaded 2 stl files arranged with all parts for follower and all parts for leader as a single tray of parts with all orientations correct.
- Uploaded gauges for lego.

## [v0.1.3] - 2024-07-18
- Uploaded Gauge_tight_1

## [v0.1.2] - 2024-07-18
- Uploaded Gauge_0

## [v0.1.1] - 2024-05-17
- Changed filenames
- Fix removable jaw `Tip_c`

## [v0.1.0] - 2024-05-16
### Changed
- **Print_SO_ARM100_05c - Moving_Jaw_04f-1**: Updated the servo attachment faces to retain parts during assembly.
- **Print_SO_ARM100_05c - Removable_Jaws_01e-1**: Clearances added to allow attachment lateral freedom at the end of the jaws - i.e. they can be screwed in the middle or to the sides.
- **Print_SO_ARM100_05c - Wrist_Roll_Pitch_04c-1**: Updated the servo attachment faces to retain parts during assembly.

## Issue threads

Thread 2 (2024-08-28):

How I integrate with e open source "Le Robot" system

feisuo, 2024-08-28:
I have printed and assembled the robotic arm, how can I run Lerobot correctly.  I found the motor config  in Lerobot project , How I config STS3215 motor
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

TheRobotStudio, 2024-08-29:
Hi, please sign up to the Le Robot Discord server linked in the ReadMe for support. Software configured for the SO-ARM will be released very soon.

pkooij, 2025-01-27:
Here you can find the tutorial on how to get started with the SO-100 and LeRobot: [https://github.com/huggingface/lerobot/blob/main/examples/10_use_so100.md](url)

Closed 2025-02-07.

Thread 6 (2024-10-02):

Alibaba link to STS3215 Servo shows "This product is no longer available."

ashwinvk94, 2024-10-02:
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

ramkumarkoppu, 2024-10-02:
Looks it is out of stock,  it may be bit more expensive to buy from other suppliers like this https://uk.robotshop.com/products/magnetic-encoding-servo-sts3215-74v-19kgcm

TheRobotStudio, 2024-10-02:
I'm not sure why that link has suddenly died. The servos are definitely in stock.

EvanMath, 2024-10-03:
Hi everyone,

I found that ordering STS3215 from AliExpress (https://www.aliexpress.com/item/1005007693922437.html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) is cheaper as the transfer costs seem to be much less. At least for Greece where I am located. And it is the same shop in both cases.

Closed 2024-10-02.

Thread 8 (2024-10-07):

Separated STL files for arm components

EvanMath, 2024-10-07:
Hi,

I would like to ask if you could provide the separated stl files for each part of each arm. I struggle to complete the full printing as I guess my bed is not perfectly flat thus some parts are not printed properly.
I tried to split them in tinkercad but it seems that I don't have the option to do it.

Regards,
V.M

TheRobotStudio, 2024-10-07:
Done

Closed 2024-10-07.

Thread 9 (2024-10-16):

Additional AUS/NZ Oceania source for waveshare boards

DingoOz, 2024-10-16:
If possible, the BOM could add a column for Australia / New Zealand (or even just Oceania)

An Australian based seller of the Waveshare servo board is:

https://core-electronics.com.au/serial-bus-servo-driver-board.html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

Price AUD$7.95 (inc GST)

TheRobotStudio, 2024-10-26:
Thanks, that's very useful.

We will add!

AlfMueller, 2025-04-30:
Waweshare Switzerland:
https://www.bastelgarage.ch/serial-bus-servo-driver-adapter-a-usb-uart
https://www.bastelgarage.ch/st3215-30kg-serial-bus-servo

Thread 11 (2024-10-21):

Open CAD files format

kolergy, 2024-10-21:
First thanks for sharing this design and including the CAD files!

However these are in the proprietary Solidworks format (.SDLPRT). Unfortunately most people do not have or can not afford Solidworks.

Would it be possible to share the CAD files in an open CAD format like STEP?

TheRobotStudio, 2024-10-26:
Yes, I will upload the STEP on Monday.

brukg, 2024-12-08:
@TheRobotStudio  It would be great if we can have the step file for each part instead of the whole model. is that possible to do?

pkooij, 2025-01-27:
I added the separate cad files

odellus, 2025-03-30:
@pkooij how big of a lift is it to ask to convert the [7 DOF SLDASM](https://github.com/TheRobotStudio/SO-ARM100/tree/main/URDF/SO_7DOF_ARM100_08h_HL_01d_URDF_01.SLDASM) model to STEP format? I'm terribly interested in the 7 DOF version and I just looked up price of solidworks so yeah. 🙏🏻

pkooij, 2025-03-31:
Hi @odellus,

That 7DOF file is an early version of HopeJr arm (I will remove it from this repo), that can now be found in this repo: https://github.com/TheRobotStudio/HOPEJr

Closed 2025-01-27.

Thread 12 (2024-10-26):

Base Idle Clap tolerances too tight

brainwavecoder9, 2024-10-26:
Probably overkill to add these as issues, and I would consider this VERY minor, but realizing that might be best way to track.

The tolerance on the base idle clamp (pictured) is too tight. When using the 3rd horn on servo 1, the clamp interferes with the horn.

Wouldn't matter if the clamp side of the horn was intended not to move, and I'm sure the servo can overcome it, but the horn is screwed onto the arm so this will cause friction.

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

TheRobotStudio, 2024-10-26:
So when you screw the clamp on it grips the extra servo horn? It should be slightly loose, just a 0.1mm clearance. If the clamp is not fully screwed down does that allow some movement? If needed I can add a bit more clearance...

brainwavecoder9, 2024-10-26:
Yes it grips tightly. I was able to carve it out to make clearance.

It's also possible it has to do with my print and/or my material possibly warping. Someone talked me into PC (do not recommend). ABS and PETG have been very good.

brainwavecoder9, 2024-10-26:
FYI Confirmed the interference with ABS also

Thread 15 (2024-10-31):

parts list quantity question

MatthewNinety, 2024-10-31:
In your parts list, it says the unit price for servos is $14.  But when I click the US alibaba link that you have listed for the servos, it says there are 6 servos per batch, and the total price is about $17 per batch, with about $12 in shipping.
That means the total price for 12 servos (17*2)  and shipping is about $50, which comes out to about $2 per servo.
This is a significant difference.  Did I make a mistake?

TheRobotStudio, 2024-11-01:
If you follow it through that 1 piece should add 6 servos to the cart and an adaptor board, now 15USD each plus tax of about 17USD.

To France where I am I get free shipping presently so the total is 103EUR.

MatthewNinety, 2024-11-09:
Thanks that solved it! I act like I've never gone shopping before :)

Closed 2024-11-09.

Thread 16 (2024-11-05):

Are these links for China Mainland the same parts as in the list?

Vacuame, 2024-11-05:
STS3215 Servo：https://item.taobao.com/item.htm?id=769061524145
Motor Control Board：https://item.taobao.com/item.htm?id=738955630278

I found these two part in chinese shop, but uncertainty about feasibility

TheRobotStudio, 2024-11-05:
They look correct - are you able to use the links on Ali provided in the readme?

Vacuame, 2024-11-06:
> They look correct - are you able to use the links on Ali provided in the readme?

I haven't tried it yet, because it says overseas buyers only. Maybe I can buy after I sign up a overseas buyer, but still too hassle.

TheRobotStudio, 2024-11-08:
That seems odd to me, I am checking with the company. You can also get in touch directly with Jenny Deng who is the sales rep that runs the Ali page: 2337371583@qq.com

I'd be interested to hear how you get on.

TheRobotStudio, 2024-11-08:
Feetech confirm that you can buy through the Taobao store for delivery to China.

Vacuame, 2024-11-26:
> Feetech confirm that you can buy through the Taobao store for delivery to China.

We have fully tested the devices in the link and confirmed that they are available, so you can now add them to the Sourcing Parts list!

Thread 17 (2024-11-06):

About Power supply

Vacuame, 2024-11-06:
Footnotes says "The 7.4V has a stall torque of 16.5kg.cm at 6V (and likely slightly less for a 5V power supply)"
So can I use 12V power supply for 7.4V STS3215 Servo (not 12V STS3215)?

Closed 2024-11-07.

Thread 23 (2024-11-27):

Waveshare ST3215 servo support

rabhishek100, 2024-11-27:
I am from India and I am able to only find the Waveshare ST3215 servo and Waveshare serial bus servo driver board locally here. Will the software work with that motor or do we need need to write a separate motor class for that to work?

TheRobotStudio, 2024-11-27:
They will work just the same.

rabhishek100, 2024-11-28:
Thanks

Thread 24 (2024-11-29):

Loose Base and Shoulder Joints Causing Vibration in Robotic Arm – Possible Solutions?

nomorewzx, 2024-11-29:
Hi, @TheRobotStudio thanks a lot for your excellent work!

After assembling my robotic arm, I noticed that the Base Rotation Joint and Shoulder Joint of followe arm are a bit loose.

Even after tightening all the screws, there’s still some play in these joints. This causes the entire arm to vibrate during teleoperation.

Could this issue possibly be caused by insufficient precision in the 3D-printed links?

Or Has anyone else encountered this issue? How did you solve it?

P.S. I am using the FeeTechSTS3215 7.4V version motors

Thanks a lot!

TheRobotStudio, 2024-11-29:
Some people have reported problems with the 12v version but I have not encountered it myself yet so I'm not clear on the causes.

Where is the looseness? Where the structure screws to the servo horns or how the servos attach to the arm itself?

nomorewzx, 2024-12-03:
@TheRobotStudio you are correct that the looseness in my video is actually the normal thing.

It turns out that the vibration is not due to any loose connection but due to the motor configuration.

I changed the minimum start force of rotation base motor and shoulder motor to 5N (16N by default) and reduced the P_coefficient to 8 (16 by default), then the vibration is almost gone.

TheRobotStudio, 2024-12-04:
Great!

Closed 2024-12-04.

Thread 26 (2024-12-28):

Question - Gripper servo load is very high when opening the gripper

nomorewzx, 2024-12-28:
Hi,

I am now trying to implment a simple force control for the gripper. I am using the "Present_Load" value to approximate the **force** that the gripper applys on objects.

However I found one interesting thing:
1. When I open the gripper, the "Present_Load" is very high, ~1042
2. When I close the gripper without touching any object, the "Present_Load" is very low, ~14

This is not a major blocker to me since the gripper works pretty well. But I am just curious if anyone else entouner this?

nomorewzx, 2025-01-03:
I found that the "Present_Load" value is signed, in an interesting way. The value consists of 2 bytes, the higher byte represents the positive/negtive and

1. when the higher bytes decimal value is 4 (binary value `00000100`), it represents a negative value.
2. when the higher bytes is 0, it represents a positive value

Closed 2025-01-03.

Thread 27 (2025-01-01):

If I'm making 2 arms, is there any reason not to by twelve of the "1 arm" servos?

jbrownkramer, 2025-01-01:
They're cheaper, and appear to be the same thing.

TheRobotStudio, 2025-01-01:
What do you mean by the 1 arm servos?

jbrownkramer, 2025-01-02:
In the read me, the parts list for two arms links to some STS3215 Servos that are $15 each, and the parts list for 1 arm is a different link to STS3215 Servos that are less than $14 each.

jbrownkramer, 2025-01-27:
Just to bump this again.  There are two different US links to the STS3215 Servos in README.md.  The first one is $15/each and the second one is < $14/each.  I ordered from the first link because it was in the part list for the building two arms, which is what I am doing.  The $15 version comes in lots of 6 with a controller board for each lot.  So when you buy 12 servos you're really buying the servos at about $14 each and about $12 for two controller boards.  But those boards are no longer used in the project.  I think the first link should be changed to point to the cheaper servos.

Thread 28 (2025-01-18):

I think the parts list has redundant parts

jbrownkramer, 2025-01-18:
Below is the first parts list on on the README.  I started by going down the list and buying all of the things I didn't already have.  However, the first link includes 2 URT-1 boards, which I believe serve the same purpose as the Motor Control Boards in the second link.  At any rate, all of the videos I watched use the URT-1 board, and not the other Motor Control Boards.  The URT-1 boards come with USB cables and the ports are not USB C, making the third link unnecessary.  The URT-1s don't have a barrel jack power supply, making the fourth link unnecessary.

It would be nice to list the requirement of a six-volt power supply with leads, since that's something I don't have.

If the linked motor-controller boards are meant as alternatives, it would be nice to have some instructions for installing drivers, which I haven't been able to find.

#### Parts For Two Arms (Standard Teleoperation Setup):
| Part | Amount | Unit Cost (US) | Buy US | Unit Cost (EU) | Buy EU |
|---|---|---|---|---|---|
| STS3215 Servo<sup>[1](#myfootnote1)</sup> | 12 | $15 | [Alibaba](https://www.alibaba.com/product-detail/6PCS-7-4V-STS3215-Servos-for_1600523509006.html) | 13€ | [Alibaba](https://www.alibaba.com/product-detail/6PCS-7-4V-STS3215-Servos-for_1600523509006.html) |
| Motor Control Board | 2 | $11 | [Amazon](https://www.amazon.com/Waveshare-Integrates-Control-Circuit-Supports/dp/B0CTMM4LWK/) | 12€ | [Amazon](https://www.amazon.fr/-/en/dp/B0CJ6TP3TP/)|
| USB-C Cable 2 pcs | 1 | $7 | [Amazon](https://www.amazon.com/Charging-etguuds-Charger-Braided-Compatible/dp/B0B8NWLLW2/?th=1) | 7€ | [Amazon](https://www.amazon.fr/dp/B07BNF842T/) |
| Power Supply<sup>[2](#myfootnote2)</sup> | 2 | $10 | [Amazon](https://www.amazon.com/Facmogu-Switching-Transformer-Compatible-5-5x2-1mm/dp/B087LY41PV/) | 13€ | [Amazon](https://www.amazon.fr/-/en/dp/B01HRR9GY4/) |
| Table Clamp 4pcs | 1 | $18 | [Amazon](https://www.amazon.com/WORKPRO-Clamps-Woodworking-One-Handed-Spreader/dp/B0CQYDJWS8/) | 21€ | [Amazon](https://www.amazon.fr/dp/B08HW9VFM8/)|
| Screwdriver Set<sup>[3](#myfootnote3)</sup> | 1 | $6 | [Amazon](https://www.amazon.com/Precision-Phillips-Screwdriver-Electronics-Computer/dp/B0DB227RTH) | 10€ | [Amazon](https://www.amazon.fr/dp/B08ZXVMVYD/) |
| Total |---| $241 |---| 244€ |---|

pkooij, 2025-01-27:
Hi, @jbrownkramer the motor control board is needed because it's supported in LeRobot [https://github.com/huggingface/lerobot/blob/main/examples/10_use_so100.md](url). It's indeed a bit confusing that the first link comes with the URT-1 boards but they are not supported there.

jbrownkramer, 2025-01-27:
Hi, @pkooij that makes sense!  In that case I would suggest changing the list in the "Parts For Two Arms" section of the README.md to match the links in the "Parts For One Arm" section, since the user can save $12 and not buy any unnecessary parts.

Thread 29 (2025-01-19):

The model in the youtube tutorial is very different from the printed model.

jbrownkramer, 2025-01-19:
I'm getting through the assembly, but mostly by looking at the picture of the assembled arm/guessing based on shapes.

jbrownkramer, 2025-01-19:
Ah ha!  There is a whole series on the assembly of the latest model, but is not linked to from this repo.

https://www.youtube.com/watch?v=temou_Nr5s8&list=PLy7gxZH9jzfR0l8fYH8C1nyEc4pxSBrer

Closed 2025-02-07.

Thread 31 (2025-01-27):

Disaster: Built following the instructions here.  Only then started following Huggingface, which says I need to modify all leader servos.

jbrownkramer, 2025-01-27:
First question: Is it strictly necessary for me to modify all leader servos?  On of your videos mentions something about setting the servos to be powered.  Could setting them to be not powered in the case of the leader help here?

Second: Rather than linking to the assembly instructions for an older version of arm, would it be better to remove the link to the servo-reprogramming video and the assembly video, and instead link to the HuggingFace instructions for this arm?

https://github.com/huggingface/lerobot/blob/main/examples/10_use_so100.md

https://www.youtube.com/watch?v=FioA2oeFZ5I&ab_channel=HuggingFace

Cadene, 2025-01-27:
> "Is it strictly necessary for me to modify all leader servos?"
No it is not, but the leader arm will be harder to move due to friction. You wont be able to teleoperate it with one hand and for a long time. We are working on an updated version of the motors to not have to remove the gears.

> "link to the HuggingFace instructions for this arm"
Yes, really sorry for the trouble. The team is growing and we finally have the human ressources to iterate on the tutorial. We want to add checks to every assembly steps to avoid any issue.

jbrownkramer, 2025-01-27:
I really appreciate the response!  I have really been enjoying building these arms and I am looking forward to doing things with them.

Closed 2025-02-07.

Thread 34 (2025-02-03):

libtiff.so.6: undefined symbol: jpeg12_write_raw_data, version LIBJPEG_8.0

ylyhlh, 2025-02-03:
after running the command in instruction
``` bash
conda install -y -c conda-forge ffmpeg
pip uninstall -y opencv-python
conda install -y -c conda-forge "opencv>=4.10.0"
```
Starting to get error, before running that, the teleoperate without camera works just fine,

> libtiff.so.6: undefined symbol: jpeg12_write_raw_data, version LIBJPEG_8.0

Full command and message:

(lerobot_new)  ~/lerobot  ↱ main ±  python lerobot/scripts/control_robot.py \
  --robot.type=so100 \
  --robot.cameras='{}' \
  --control.type=teleoperate
Traceback (most recent call last):
  File "/home/martinliuhao/lerobot/lerobot/scripts/control_robot.py", line 133, in <module>
    from lerobot.common.robot_devices.control_utils import (
  File "/home/martinliuhao/lerobot/lerobot/common/robot_devices/control_utils.py", line 13, in <module>
    import cv2
  File "/home/martinliuhao/miniconda3/envs/lerobot_new/lib/python3.10/site-packages/cv2/__init__.py", line 181, in <module>
    bootstrap()
  File "/home/martinliuhao/miniconda3/envs/lerobot_new/lib/python3.10/site-packages/cv2/__init__.py", line 153, in bootstrap
    native_module = importlib.import_module("cv2")
  File "/home/martinliuhao/miniconda3/envs/lerobot_new/lib/python3.10/importlib/__init__.py", line 126, in import_module
    return _bootstrap._gcd_import(name[level:], package, level)
ImportError: /home/martinliuhao/miniconda3/envs/lerobot_new/lib/python3.10/site-packages/cv2/python-3.10/../../../.././libtiff.so.6: undefined symbol: jpeg12_write_raw_data, version LIBJPEG_8.0

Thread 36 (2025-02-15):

PSU clarity.

mikegc-aws, 2025-02-15:
Could we add a little more info on the PSU. The listed units in the BOM are 5v4a (right?). The controller board asks for 9-12v. Can anyone with deeper knowledge than me help to clarify the specs of the PSU needed, and maybe why that is the case. E.g. If I have a 12v2a PSU is that okay?

I will continue to research too.

I see the notes at the end of the BOM but this is not quite enough to answer this question.

Thanks

odellus, 2025-03-30:
Same here. I've opted for the 12V servos and honestly I'd like to go up to a 12V PSU with more than 5A but the controllers are DC5521 and every 12V 8A PSU uses DC5525 connectors. Wondering if there is an equivalent servo board for controlling 6+ STS3215 12V servos (there's a 7 DOF SO-ARM100 in the URDFs).

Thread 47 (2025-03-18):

Duplicate part Wrist_Roll_Pitch_08i-1 on Print_Leader_Bambu_P1P.3mf

SRombauts, 2025-03-18:
Hi,

I printed all the parts using the 3MF files from #30 Optimized print files for popular printer Bambu P1P by @philfung

But then I found that there is duplicated part in the stl_files_for_3dprinting/Leader/Print_Leader_Bambu_P1P.3mf
It contains two instances of Print_Follower_SO_ARM100_08k_UP_Prusa - Wrist_Roll_Pitch_08i-1.STL, one on each plate:
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
In fact, the duplication is also visible in the first screenshot of the PR #30.

If I compare to the list of individual STL files for the Leader, it contains only one Wrist_Roll_Pitch_08i https://github.com/TheRobotStudio/SO-ARM100/tree/main/stl_files_for_3dprinting/Individual/Leader (like the Follower)

Best,
Sébastien

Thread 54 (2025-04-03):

Improved URDF

StoneT2000, 2025-04-03:
thanks for the great low-cost SO100 arm, been having a lot a fun playing with it recently.

I have interest in doing sim2real / simulation heavy experiments and found that the URDF in this repo is not well defined (missing joint limits / some joint axes are inverted, and lack of decomposed collision meshes)

I have a fixed version in my own github repo, happy to make a PR for it here. I saw some people having trouble importing it into their own sims on discord earlier.

shareshareneed, 2025-04-06:
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

Hello, may I ask which UPDF improvement project you are working on? I just started to contact this project recently, and I would like to refer to your improvement work

StoneT2000, 2025-04-06:
https://github.com/haosulab/ManiSkill/tree/main/mani_skill/assets/robots/so100 modified URDF here

just added so100 to my labs simulation framework for training/evaluation experiments and sim2real

pkooij, 2025-04-22:
Hi @StoneT2000, that's very nice would you like to make a PR?

StoneT2000, 2025-05-08:
Yes I'll make a PR this week.

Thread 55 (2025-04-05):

Webcam_Mount_Wrist v2.stl does not match pictures

RASPIAUDIOadmin, 2025-04-05:
Hi
Webcam_Mount_Wrist v2.stl does not match [pictures ](https://github.com/TheRobotStudio/SO-ARM100/blob/main/media/cam_mount2.jpg)and does not connect to Optional/Camera_Holder/stl/Updated_Wrist_Camera_Insert.stl

Optional/Wrist_Cam_Mount_Vinmooog_Webcam/stl/Webcam_Mount_Wrist v2.stl

thx

LaurentBerger, 2025-04-24:
Yes I can confirm there is a problem. How can you fix camera on wrist? @pkooij

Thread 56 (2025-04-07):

servo strength arm size ratio

wibed, 2025-04-07:
has any one of the engineers any idea about the ratio between the strength of the servo and the arm size
for most efficient strong movement

wibed, 2025-04-07:
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

wibed, 2025-04-07:
how to go for very heavy objects? which parts

wibed, 2025-04-07:
here is an upgrade in this direction.

https://www.youtube.com/watch?app=desktop&v=b5HZOQ87Nsg

are there more?

pkooij, 2025-04-22:
The 7.4V arm lifts around 200g roughly, and the 12V 300 gram. But it is depending on the orientation of the robot.

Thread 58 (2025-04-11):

3D printing Infill density

joonsu0109gh, 2025-04-11:
Is the 13% infill density for 3d printing correct?
The .3mf file for the Bambu X Series has the infill density set to 30%, so I wanted to confirm.

Thank you for the awesome work!

pkooij, 2025-04-22:
Yes that is correct, although 15% and even 20% is okey

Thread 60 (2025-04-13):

GripperLeader calibration error

correderadiego, 2025-04-13:
I am having issues calibrating the leader board. I have managed to mount both arms but in the calibration process I am having the following error. I have tested with different servos in the gripper and the result is the same.

Do you have any idea? Thanks for all and for this amazing project. :)

python lerobot/scripts/control_robot.py --robot.type so100 --control.type teleoperate
INFO 2025-04-13 15:42:29 ol_robot.py:353 {'control': {'display_cameras': True, 'fps': None, 'teleop_time_s': None},
 'robot': {'calibration_dir': '.cache/calibration/so100',
           'cameras': {'laptop': {'camera_index': 0,
                                  'channels': 3,
                                  'color_mode': 'rgb',
                                  'fps': 30,
                                  'height': 480,
                                  'mock': False,
                                  'rotation': None,
                                  'width': 640},
                       'phone': {'camera_index': 2,
                                 'channels': 3,
                                 'color_mode': 'rgb',
                                 'fps': 30,
                                 'height': 480,
                                 'mock': False,
                                 'rotation': None,
                                 'width': 640}},
           'follower_arms': {'main': {'mock': False,
                                      'motors': {'elbow_flex': [3, 'sts3215'],
                                                 'gripper': [6, 'sts3215'],
                                                 'shoulder_lift': [2,
                                                                   'sts3215'],
                                                 'shoulder_pan': [1, 'sts3215'],
                                                 'wrist_flex': [4, 'sts3215'],
                                                 'wrist_roll': [5, 'sts3215']},
                                      'port': '/dev/ttyACM0'}},
           'gripper_open_degree': None,
           'leader_arms': {'main': {'mock': False,
                                    'motors': {'elbow_flex': [3, 'sts3215'],
                                               'gripper': [6, 'sts3215'],
                                               'shoulder_lift': [2, 'sts3215'],
                                               'shoulder_pan': [1, 'sts3215'],
                                               'wrist_flex': [4, 'sts3215'],
                                               'wrist_roll': [5, 'sts3215']},
                                    'port': '/dev/ttyACM1'}},
           'max_relative_target': None,
           'mock': False}}
Connecting main follower arm.
Connecting main leader arm.
Activating torque on main follower arm.
**Wrong motor position range detected for gripper. Expected to be in nominal range of [0, 100] % (a full linear translation), with a maximum range of [-10, 110] % to account for some imprecision during calibration, but present value is -127.23577117919922 %.** This might be due to a cable connection issue creating an artificial jump in motor values. You need to recalibrate by running: `python lerobot/scripts/control_robot.py calibrate`
Traceback (most recent call last):
  File "/home/ziash/lerobot/lerobot/common/robot_devices/motors/feetech.py", line 397, in apply_calibration_autocorrect
    values = self.apply_calibration(values, motor_names)
  File "/home/ziash/lerobot/lerobot/common/robot_devices/motors/feetech.py", line 467, in apply_calibration
    raise JointOutOfRangeError(
lerobot.common.robot_devices.motors.feetech.JointOutOfRangeError: Wrong motor position range detected for gripper. Expected to be in nominal range of [0, 100] % (a full linear translation), with a maximum range of [-10, 110] % to account for some imprecision during calibration, but present value is -127.23577117919922 %. This might be due to a cable connection issue creating an artificial jump in motor values. You need to recalibrate by running: `python lerobot/scripts/control_robot.py calibrate`

During handling of the above exception, another exception occurred:

Traceback (most recent call last):
  File "/home/ziash/lerobot/lerobot/scripts/control_robot.py", line 373, in <module>
    control_robot()
  File "/home/ziash/lerobot/lerobot/configs/parser.py", line 120, in wrapper_inner
    response = fn(cfg, *args, **kwargs)
  File "/home/ziash/lerobot/lerobot/scripts/control_robot.py", line 360, in control_robot
    teleoperate(robot, cfg.control)
  File "/home/ziash/lerobot/lerobot/common/robot_devices/utils.py", line 28, in wrapper
    raise e
  File "/home/ziash/lerobot/lerobot/common/robot_devices/utils.py", line 24, in wrapper
    return func(robot, *args, **kwargs)
  File "/home/ziash/lerobot/lerobot/scripts/control_robot.py", line 205, in teleoperate
    control_loop(
  File "/home/ziash/lerobot/lerobot/common/datasets/image_writer.py", line 36, in wrapper
    raise e
  File "/home/ziash/lerobot/lerobot/common/datasets/image_writer.py", line 29, in wrapper
    return func(*args, **kwargs)
  File "/home/ziash/lerobot/lerobot/common/robot_devices/control_utils.py", line 216, in control_loop
    robot.connect()
  File "/home/ziash/lerobot/lerobot/common/robot_devices/robots/manipulator.py", line 272, in connect
    self.leader_arms[name].read("Present_Position")
  File "/home/ziash/lerobot/lerobot/common/robot_devices/motors/feetech.py", line 757, in read
    values = self.apply_calibration_autocorrect(values, motor_names)
  File "/home/ziash/lerobot/lerobot/common/robot_devices/motors/feetech.py", line 400, in apply_calibration_autocorrect
    self.autocorrect_calibration(values, motor_names)
  File "/home/ziash/lerobot/lerobot/common/robot_devices/motors/feetech.py", line 553, in autocorrect_calibration
    raise ValueError(f"No integer found between bounds [{low_factor=}, {upp_factor=}]")
ValueError: No integer found between bounds [low_factor=np.float32(0.15283203), upp_factor=np.float32(0.27294922)]

correderadiego, 2025-04-13:
I have been making some tests and I think that I found my issue. My grip is giving me more than the 100 degrees of freedom that the grip needs. So If I try to make the calibration with it it fails.

The solution will be modifying this limit or just adjust the hardware limit of the grip.

DipFlip, 2025-04-21:
I'm getting the same error when running the calibration
```bash
ValueError: No integer found between bounds [low_factor=np.float32(0.018066406), upp_factor=np.float32(0.018066406)]
```
Not sure I understand what you describe @correderadiego . Did you figure it out?

correderadiego, 2025-04-23:
My problem was that the grip gaves a wider angle that the software limits.
So I modify the feedtech class with my new limits. I increase the limits
step by step útil the error desapears.

El lun, 21 abr 2025, 9:15, Emil Rofors ***@***.***> escribió:

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

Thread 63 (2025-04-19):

Cannot insert my servo motor to the base printed in Bambu Lab P1S

ywiyogo, 2025-04-19:
@philfung ,
I've already printed the parts using the file Print_Leader_Bambu_P1P.3mf with Bambu Lab P1S. However, I cannot insert the servo motor to the base. It's just around 0.5 mm too tight.

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

I tested the gauge zero from stl_files_for_3dprinting/Gauges/Gauge_0.STL and it fits well.

The printer setting is as recommended in the README:
* Material: PLA
* Nozzle Diameter and Precision: 0.4mm nozzle diameter at 0.2mm layer height.

What did I do wrong and which setting should I check in my printer?

Thanks!

philfung, 2025-04-19:
@ywiyogo hm, thanks for the report.  I've used this file to print 8 different arms, and the servo fits correctly when i use it (though I sometimes have to push it in with a lot of force).  Does the servo not fit at all, even with force?   If it doesn't fit at all, then I can try to print again and check.

ywiyogo, 2025-04-20:
Hi @philfung , yes even with a huge force, it got stuck and leaves about 0.5 cm space to the end. Then, I need to use a tool and huge force to pull my servo motor from the base. I thought your file will be fit for P1S too. I'll do some experiment to find out the cause of this issue.
I tried to mount the second part without the motor and it doesn't fit too.

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

philfung, 2025-04-20:
I'm sorry for this.  Ill try to print out a part in the next few days and see what's wrong

ywiyogo, 2025-04-20:
I think, I see the issue.
The servo motor has 24.72 mm witdh and 35 mm height on the back, like the following dimension from the specification:

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

My measurement in the base model shows 24.70 mm for the width and 32.90 mm height. The different in height is 2 mm and 0.02 mm in the width.

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

In another parts I see smaller dimension than the real dimension of the servo motor.

I check the diff in the history, and it shows that all the measurements in the base model are from the beginning the same. Thus, I wonder how many people don't have the issue during the assembly of this robot.

philfung, 2025-04-20:
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

Hi @ywiyogo , I just did a fresh print using the checked in pmf file on a Bambu P1P with PLA.  It fits fine with both a Waveshare 3215 (the servo you're using) and the Feetech 3215 (the recommended servo).  In addition I've known several others who've printed out using this file.

jbcayrou, 2025-04-21:
Hi!

I’m having the same issues as @ywiyogo . I had some trouble fitting the base with the motor 1 blocker (Base_08q-5.STL). The most difficult part for me was the Wrist_Roll_Pitch_08i-1.STL. I'm using a Creality K1C printer with PLA.

I managed to assemble the parts by sanding down the small corners where they were rubbing, but the fit is still very tight and requires a lot of force.
Is there a specific reason why the fit is so tight (the sides seem slightly smaller than the servo)?

Do you have additional settings on your printer?

philfung, 2025-04-23:
@jbcayrou hm, the pmf has all the settings (at least form Bambu P1P).
@jbcayrou @ywiyogo One "hacky" solution is to edit the file slightly in a CAD program to make the opening bigger for your printers (For your convenience, here is a [CAD](https://www.tinkercad.com/things/ldsY0DOvMv6/edit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) file with the base, wrist and feetech servo which you can edit).

ywiyogo, 2025-04-24:
@jbcayrou thanks for sharing. As, I've been pointed out above that the opening in the model doesn't fit to the dimension of the servo motor. The 2 screenshots above is from BambuStudio and in FreeCAD is the same.
@philfung yes, I'm working to modify the opening for the servo motor in FreeCAD. Thanks for the CAD file.

dmosher42, 2025-05-09:
@philfung @ywiyogo
Before editing the CAD file, you may want to try changing the [XY hole/contour compensation settings](https://wiki.bambulab.com/en/software/bambu-studio/xy-hole-contour-compensation) in Bambu Studio.

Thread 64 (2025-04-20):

Floating cantilever issue with Bambu X1C follower arm 3D print

bicepjai, 2025-04-20:
The object `Print_Follower_SO_ARM100_08k_UP_Prusa - Rotation_Pitch_08i-1.stl`
from `Print_Follower_Bambu_P1P.3mf`
always complains that it has floating cantilever and asks for reorientation.
Any suggestion on how to update ? I am using Bambulabs X1C.

bicepjai, 2025-04-27:
One of the object was not selected in the options and the slicer was showing that it was not sliced properly.
So just enable ; just click on the burger option and them select the missed option before slicing and things are back to normal with no warnings.

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

Closed 2025-04-27.

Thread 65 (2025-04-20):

Help needed with setting when printing LeRobot Arm using PETG rather than PLA Basic

bicepjai, 2025-04-20:
Trying to print the follower arm from file [stl_files_for_3dprinting/Leader](https://github.com/TheRobotStudio/SO-ARM100/tree/main/stl_files_for_3dprinting/Leader)
Can someone help with how to update the slicer for good quality print using PETG on bambulabs X1C ?
The file is for PLA Basic

Posted my question also on [reddit](https://www.reddit.com/r/3Dprinting/comments/1k3v39u/help_printing_lerobot_arm_using_petg_rather_than/
)

dmosher42, 2025-05-09:
If you are following the Bambu Studio Quickstart guide, [they explain how to do so here in step 2](https://wiki.bambulab.com/en/software/bambu-studio/studio-quick-start#select-printerfilamentprocess-presets).

If PETG isn't an option, you probably didn't set it up [during the initial setup](https://wiki.bambulab.com/en/software/bambu-studio/studio-quick-start#filament-selection) and will need to do so.

Note that different manufacturer's filaments can differ in composition (usually addatoves), so if you are using a filament not listed, you may want to do some tests first or print each part separately.

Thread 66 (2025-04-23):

Issue with SO100 Robot: Motor #2 (shoulder_lift) Overload

romanovvv1987, 2025-04-23:
During both recording and replay operations, the shoulder_lift motor (#2) of the SO100 robot experiences intermittent overloads and disconnects. The issue occurs even when other motors are functioning normally. This happens approximately every other movement attempt.

Qu3tzal, 2025-05-21:
Put the motor in a different joint and retry. It's likely your motor has an issue, you just need to buy another one.

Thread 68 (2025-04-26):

Overhead Camera Mount unavailable for Europe

Yanis-Bouchelaghem, 2025-04-26:
Hello!

Thank you all for this amazing repo, and thank you @cmcgartoll for providing the [overhead camera mount design](https://github.com/TheRobotStudio/SO-ARM100/blob/main/Optional/Overhead_Cam_Mount/README.md).

However, the link for the [recommended camera](https://www.amazon.com/dp/B082X91MPP) is not available for europe. I am having a hard time finding the same camera model from the same manufacturer "XPCAM" in europe.

Could anyone please recommend an alternative camera that is compatible with the overhead camera mount design ?

Could I also suggest maybe having an alternative mount design that works with [camera modules](https://www.amazon.com/innomaker-Computer-Raspberry-Support-Windows/dp/B0CNCSFQC1/132-7372155-9780230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) used for the [wrist cameras](https://github.com/TheRobotStudio/SO-ARM100/tree/main/Optional/Wrist_Cam_Mount_32x32_UVC_Module) ?

Thank you.

GuillaumeVW, 2025-04-29:
I'm planning on modifying the existing overhead mount design to work with the [Vinmooog Webcam](https://www.amazon.com.be/gp/product/B0BG1YJWFN).
This is the same camera used in [one of the optional wrist cam designs](https://github.com/TheRobotStudio/SO-ARM100/tree/main/Optional/Wrist_Cam_Mount_Vinmooog_Webcam).
Once I have a working modification for the overhead mount, I can share the updated files if there's interest.

philfung, 2025-04-29:
> maybe having an alternative mount design that works with camera modules

++ agree that an overhead mount that allows a plug-in 32x32 camera module would be most scalable + universal
@cmcgartoll what do you think ?

philfung, 2025-04-29:
@Yanis-Bouchelaghem as another alternative, i'm 80% sure this [cam](https://fr.aliexpress.com/item/1005006949399519.html) will yield similar results to the US cam, as they are similar in dimension

cmcgartoll, 2025-04-29:
@philfung, the 32x32 would be a nice addition to the overhead camera although FOV may be weird. I can work on that.

I will also just open source the STEP/Inventor files so anyone can build on it. @GuillaumeVW that might be helpful to you so you can more easily build on top of it!

Yanis-Bouchelaghem, 2025-05-01:
I have just ordered the [alternative camera](https://fr.aliexpress.com/item/1005006949399519.html) you suggested @philfung, I will let you know if it is compatible once I receive it.

Thank you for the suggestion! I am also looking forward to the alternative designs for the overhead mount.

philfung, 2025-05-06:
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

Yanis-Bouchelaghem, 2025-05-22:
Hello,

> [@Yanis-Bouchelaghem](https://github.com/Yanis-Bouchelaghem) as another alternative, i'm 80% sure this [cam](https://fr.aliexpress.com/item/1005006949399519.html) will yield similar results to the US cam, as they are similar in dimension

Unfortunately, the camera suggested by @philfung fits the overhead mount, but has an extremely small POV, I can confirm that this specific camera is inadequate.

The new [32x32 UVC camera module design](https://github.com/TheRobotStudio/SO-ARM100/pull/88) looks much better suited. I will print it and try it soon.

Thank you for the contribution !

I will now close this issue.

philfung, 2025-05-22:
@Yanis-Bouchelaghem my deep apologies that this suggestion didn't work out.  Have you tried increasing the resolution of the camera (1280 x 800)?  This will increase FOV.

https://github.com/huggingface/lerobot/blob/main/lerobot%2Fcommon%2Frobot_devices%2Frobots%2Fconfigs.py#L256

"Downside" is the camera training files will be slightly bigger.

Closed 2025-05-22.

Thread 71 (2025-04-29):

SO-100 components(without 3D Parts) can be used for So-101?

Huangruopeng, 2025-04-29:
I just bought SO-ARM100 Servo Motor Kit (Without 3D Printed Parts).
Can I equip it with New SO-101 3D printed parts?

pkooij, 2025-04-29:
Yes you can! From the motors perspective only the leader arm motors for SO-101 are differently geared

acyanbird, 2025-05-03:
@pkooij Hi that might be a silly question. I have a pair of ( follower and leader ) arm, and I want to update to so101 version. But how can I modify the gear ratio base on the so100 leader arm's servo?

matbee-eth, 2025-05-05:
> [@pkooij](https://github.com/pkooij) Hi that might be a silly question. I have a pair of ( follower and leader ) arm, and I want to update to so101 version. But how can I modify the gear ratio base on the so100 leader arm's servo?

you'd need the replacement gears- or purchase the kit from alibaba

mazytomo, 2025-05-06:
Hi, let me see if I am understanding correctly.

I have twelve 12v motors for SO100, which means I have to buy six 7.4v motors for the leader arm, right?
 > the leader arm is always 7.4v for the SO101.

Huangruopeng, 2025-05-15:
> > [@pkooij](https://github.com/pkooij) Hi that might be a silly question. I have a pair of ( follower and leader ) arm, and I want to update to so101 version. But how can I modify the gear ratio base on the so100 leader arm's servo?
>
> you'd need the replacement gears- or purchase the servo kit from alibaba

So the leader servo is different? Can you list servo brand and version? Thank you so much? or how to replace gears?

dannyyy, 2025-09-13:
I also have the Motor Kit with 12x 7.4V (C001). For the follower arm, no change is required.

What happens if I use the same gear for all motors in the leader arm? Do I need to adjust something in the software (servo register), calibration, ...?

Or is it impossible to use these motors for the leader arm?

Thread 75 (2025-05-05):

Manual Leader Calibration

matbee-eth, 2025-05-05:
Is it possible to simply rotate each servo to its maximum CW/CCW rotation and use that for calibration instead of/along-side the 3-pose calibration?

I believe I rotated some of my servos before assembly so some of them act up.

pkooij, 2025-05-09:
Yes this is something we are working on and will be released in the coming weeks

matbee-eth, 2025-05-09:
Until then, is there a way to monitor a motors current position and set it as its "zero" or whatever formula the calibration scripts output?

pkooij, 2025-05-22:
Hi @matbee-eth If you now recalibrate both arms with LeRobot it should be fixed, we added an additional calibration step (first step) where you need to place the robot in center position for each joint.

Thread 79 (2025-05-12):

What's the difference of the two URDFS of 05d and 8j

ZhangCYG, 2025-05-12:
We bought one with strengthened motor. But I don't know whether it is 05d or 8j. What's the difference?

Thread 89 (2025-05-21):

SO101 Error

sparkjune, 2025-05-21:
Hello guys,

SO101 arm error  as follow,

Error start -----------------------------------------------------------------------------------------------------------

Calibration file not found '.cache\calibration\so101\main_follower.json'
Connecting main follower arm.
Connecting main leader arm.
Missing calibration file '.cache\calibration\so101\main_follower.json'
Traceback (most recent call last):
  File "E:\embodiedAI\vla\lerobot\lerobot\scripts\control_robot.py", line 476, in <module>
    control_robot()
  File "D:\lh\anaconda\envs\lerobot\lib\site-packages\lerobot\configs\parser.py", line 227, in wrapper_inner
    response = fn(cfg, *args, **kwargs)
  File "E:\embodiedAI\vla\lerobot\lerobot\scripts\control_robot.py", line 447, in control_robot
    calibrate(robot, cfg.control)
  File "D:\lh\anaconda\envs\lerobot\lib\site-packages\lerobot\common\robot_devices\utils.py", line 42, in wrapper
    raise e
  File "D:\lh\anaconda\envs\lerobot\lib\site-packages\lerobot\common\robot_devices\utils.py", line 38, in wrapper
    return func(robot, *args, **kwargs)
  File "E:\embodiedAI\vla\lerobot\lerobot\scripts\control_robot.py", line 228, in calibrate
    robot.connect()
  File "D:\lh\anaconda\envs\lerobot\lib\site-packages\lerobot\common\robot_devices\robots\manipulator.py", line 256, in connect
    self.activate_calibration()
  File "D:\lh\anaconda\envs\lerobot\lib\site-packages\lerobot\common\robot_devices\robots\manipulator.py", line 331, in activate_calibration
    calibration = load_or_run_calibration_(name, arm, "follower")
  File "D:\lh\anaconda\envs\lerobot\lib\site-packages\lerobot\common\robot_devices\robots\manipulator.py", line 321, in load_or_run_calibration_
    calibration = run_arm_manual_calibration(arm, self.robot_type, name, arm_type)
  File "D:\lh\anaconda\envs\lerobot\lib\site-packages\lerobot\common\robot_devices\robots\feetech_calibration.py", line 443, in run_arm_manual_calibration
    if (arm.read("Torque_Enable") != TorqueMode.DISABLED.value).any():
  File "D:\lh\anaconda\envs\lerobot\lib\site-packages\lerobot\common\robot_devices\motors\feetech.py", line 751, in read
    raise ConnectionError(
ConnectionError: Read failed due to communication error on port COM8 for group_key Torque_Enable_shoulder_pan_shoulder_lift_elbow_flex_wrist_flex_wrist_roll_gripper: [TxRxResult] There is no status packet!

Error end------------------------------------------------------------------------------------------------------------------------------

I learned that it was the wiring that was loose, but I checked and didn't find it， somebody know ，how to fix it？and how to check it？

pkooij, 2025-05-22:
@sparkjune You can best check it by looking at the motor led. Start at the base and look if the motor led is on. Then move up each motor, if one is off then you know which cable is loose.

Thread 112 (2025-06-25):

Any chance of updating the URDFs for the SO ARM 100/101 with a camera mount?

miguelalonsojr, 2025-06-25:
Any chance of updating the URDFs for the SO ARM 100/101 with a camera mount? I've been working on simulating the SO ARM in Isaac Lab, which works great. However, collecting additional images from the wrist cam during simulation would be of great benefit.

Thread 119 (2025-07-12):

[low priority] Mount Helper part is not oriented optimally for printing

cHemingway, 2025-07-12:
Thanks for this project, its been great fun working through the prints, and there is lots of guidance for most parts.

However, I noticed the [Mount Helper](Optional/Mount_Helper/stl/mount_helper v2.stl) part is designed with teardrop holes, but these do not match its default Z orientation, nor are they the right way up for fastest printing (the largest flat side should be on the buildplate I think).

If we could turn the hole around, it wouldn't need supports. TBH I'm not sure if the hole is even needed? I don't see it being used in the video.

Tagging @fred3105 as he uploaded the file. Do you have the original CAD? I would be very happy to contribute an updated version if you can provide it, even the STEP file would do.

Print times on my Prusa Mini+ with a 0.6mm nozzle, 0.4mm layer height as follows:

Here is the original orientation with supports, **2.5 hours**:

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

Here is it in an optimal orientation, with no supports, **1.15 hours**

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

fred3105, 2025-09-25:
Hey @cHemingway,

I sent the step file to the email address on your GitHub profile
As @dmosher42 mentions, I simply added a plastic block to the small elbow piece, nothing fancy,

You're more than welcome to improve it

cHemingway, 2025-09-29:
Thanks for the CAD!

Remodelling it to remove the holes (I kept all other dimensions), it actually only saves 15 minutes (1h31 to 1h15m ~20%) with organic supports. Less of a saving than I expected

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

However, if I make the base a bit thinner (6mm instead of 10mm) this saves another 15 minutes, so its down to 1 hour from 1.5 hours. I don't know why the base is quite that thick, seems like thinner might work.

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

I can put the new CAD in a pull request if you like? I will print it out first and test it if so.

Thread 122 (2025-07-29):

Proper list of individual parts to print for follower arm

kevinhelvig, 2025-07-29:
Hi !
Thanks for the project,
I have a question : can you provide a proper list of which stl files to print for the follower arm SO-Arm 101 in this folder : https://github.com/TheRobotStudio/SO-ARM100/tree/main/STL/SO101/Individual

I want to use a 3D printing provider but this section looks out-dated: https://github.com/TheRobotStudio/SO-ARM100/blob/main/3DPRINT.md

Thanks !

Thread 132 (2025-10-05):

Daisy chaining power and using a 5A 12V power supply seems insufficient for full utilization

rabhishek100, 2025-10-05:
When the SO-ARM100 is built with STS/Feetech ST3215 (30 kg·cm, 12 V) servos, the current guidance of using a 12 V / 5 A PSU and daisy-chaining power through the 3-pin jumpers seems insufficient for full-load use. Under realistic heavy moves (multiple joints accelerating or holding near stall), the bus can brown-out and the first few jumpers/connectors in the chain are forced to carry the downstream current, which exceeds their safe rating.

### Evidence / Calculations

ST3215 key specs (12 V setup):

  Stall current ≈ 2.7 A per servo
  No-load current ≈ 0.18 A per servo
  Torque constant ≈ 11 kg·cm/A

Daisy-chaining power through small 3-pin cables concentrates the **sum current** into the first link(s). Typical connectors/wires in these jumpers are ~2–3 A/pin and ~AWG 26–24; forcing 8–16 A through any one segment risks **overheating, voltage drop, and resets.

Impact Observed / Likely

Voltage sag / brown-outs** during simultaneous joint motion or when holding load at reach
Servo resets / misposition** under acceleration
Hot jumpers/connectors** at the start of the chain
Limits on achievable speed/accel/payload compared with the mechanical capability

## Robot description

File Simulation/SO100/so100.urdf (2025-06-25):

<?xml version='1.0' encoding='utf-8'?>
<robot name="so_arm100">
  
  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
  <link name="base">
    <inertial>
      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
      <mass value="1.0"/>
      <origin xyz="0 0 0" rpy="0 0 0"/>
      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
    </inertial>
    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
  </link>

  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
  <link name="shoulder">
    <inertial>
      <mass value="0.119226"/>
      <origin xyz="-9.07886e-05 0.0590972 0.031089" rpy="0 0 0"/>
      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
    </inertial>
    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
  </link>

  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
  <link name="upper_arm">
    <inertial>
      <mass value="0.162409"/>
      <origin xyz="-1.72052e-05 0.0701802 0.00310545" rpy="0 0 0"/>
      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
    </inertial>
    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
  </link>

  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
  <link name="lower_arm">
    <inertial>
      <mass value="0.147968"/>
      <origin xyz="-0.00339604 0.00137796 0.0768007" rpy="0 0 0"/>
      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
    </inertial>
    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
  </link>

  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
  <link name="wrist">
    <inertial>
      <mass value="0.0661321"/>
      <origin xyz="-0.00852653 -0.0352279 -2.34622e-05" rpy="0 0 0"/>
      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
    </inertial>
    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
  </link>

  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
  <link name="gripper">
    <inertial>
      <mass value="0.0929859"/>
      <origin xyz="0.00552377 -0.0280167 0.000483583" rpy="0 0 0"/>
      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
    </inertial>
    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
  </link>

  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
  <link name="jaw">
    <inertial>
      <mass value="0.0202444"/>
      <origin xyz="-0.00161745 -0.0303473 0.000449646" rpy="0 0 0"/>
      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
    </inertial>
    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
  </link>


  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
  <joint name="shoulder_pan" type="revolute">
    <parent link="base"/>
    <child link="shoulder"/>
    <origin xyz="0 -0.0452 0.0165" rpy="1.57079 0 0"/>
    <axis xyz="0 1 0"/>
    <limit lower="-2" upper="2" effort="35" velocity="1"/>
  </joint>

  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
  <joint name="shoulder_lift" type="revolute">
    <parent link="shoulder"/>
    <child link="upper_arm"/>
    <origin xyz="0 0.1025 0.0306" rpy="-1.8 0 0"/>
    <axis xyz="1 0 0"/>
    <limit lower="0" upper="3.5" effort="35" velocity="1"/>
  </joint>

  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
  <joint name="elbow_flex" type="revolute">
    <parent link="upper_arm"/>
    <child link="lower_arm"/>
    <origin xyz="0 0.11257 0.028" rpy="1.57079 0 0"/>
    <axis xyz="1 0 0"/>
    <limit lower="-3.14158" upper="0" effort="35" velocity="1"/>
  </joint>

  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
  <joint name="wrist_flex" type="revolute">
    <parent link="lower_arm"/>
    <child link="wrist"/>
    <origin xyz="0 0.0052 0.1349" rpy="-1 0 0"/>
    <axis xyz="1 0 0"/>
    <limit lower="-2.5" upper="1.2" effort="35" velocity="1"/>
  </joint>

  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
  <joint name="wrist_roll" type="revolute">
    <parent link="wrist"/>
    <child link="gripper"/>
    <origin xyz="0 -0.0601 0" rpy="0 1.57079 0"/>
    <axis xyz="0 1 0"/>
    <limit lower="-3.14158" upper="3.14158" effort="35" velocity="1"/>
  </joint>

  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
  <joint name="gripper" type="revolute">
    <parent link="gripper"/>
    <child link="jaw"/>
    <origin xyz="-0.0202 -0.0244 0" rpy="0 3.14158 0"/>
    <axis xyz="0 0 1"/>
    <limit lower="-0.2" upper="2.0" effort="35" velocity="1"/>
  </joint>

  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

</robot>

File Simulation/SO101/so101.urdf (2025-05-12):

<?xml version="1.0" ?>
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
<robot name="so101">
  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
  <link name="base">
    <inertial>
      <origin xyz="0.020739 0.00204287 0.065966" rpy="0 0 0"/>
      <mass value="0.147"/>
      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
    </inertial>
    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
  </link>
  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
  <link name="base">
    <origin xyz="0 0 0" rpy="0 -0 0"/>
    <inertial>
      <origin xyz="0 0 0" rpy="0 0 0"/>
      <mass value="1e-9"/>
      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
    </inertial>
  </link>
  <joint name="base_frame" type="fixed">
    <origin xyz="0.020791 0.0157608 0.0324817" rpy="-3.14159 -9.52796e-30 -2.64454e-46"/>
    <parent link="base"/>
    <child link="base"/>
    <axis xyz="0 0 0"/>
  </joint>
  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
  <link name="shoulder">
    <inertial>
      <origin xyz="-0.0307604 -1.66727e-05 -0.0252713" rpy="0 0 0"/>
      <mass value="0.100006"/>
      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
    </inertial>
    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
  </link>
  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
  <link name="upper_arm">
    <inertial>
      <origin xyz="-0.0898471 -0.00838224 0.0184089" rpy="0 0 0"/>
      <mass value="0.103"/>
      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
    </inertial>
    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
  </link>
  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
  <link name="lower_arm">
    <inertial>
      <origin xyz="-0.0980701 0.00324376 0.0182831" rpy="0 0 0"/>
      <mass value="0.104"/>
      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
    </inertial>
    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
  </link>
  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
  <link name="wrist">
    <inertial>
      <origin xyz="-0.000103312 -0.0386143 0.0281156" rpy="0 0 0"/>
      <mass value="0.079"/>
      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
    </inertial>
    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
  </link>
  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
  <link name="gripper">
    <inertial>
      <origin xyz="0.000213627 0.000245138 -0.025187" rpy="0 0 0"/>
      <mass value="0.087"/>
      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
    </inertial>
    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
  </link>
  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
  <link name="gripper">
    <origin xyz="0 0 0" rpy="0 -0 0"/>
    <inertial>
      <origin xyz="0 0 0" rpy="0 0 0"/>
      <mass value="1e-9"/>
      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
    </inertial>
  </link>
  <joint name="gripper_frame" type="fixed">
    <origin xyz="-0.0079 -0.000218121 -0.0981274" rpy="-1.5708 -0 -1.5708"/>
    <parent link="gripper"/>
    <child link="gripper"/>
    <axis xyz="0 0 0"/>
  </joint>
  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
  <link name="moving_jaw_so101_v1">
    <inertial>
      <origin xyz="-0.00157495 -0.0300244 0.0192755" rpy="0 0 0"/>
      <mass value="0.012"/>
      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
    </inertial>
    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
  </link>
  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
  <joint name="6" type="revolute">
    <origin xyz="0.0202 0.0188 -0.0234" rpy="1.5708 4.00612e-15 -2.2678e-16"/>
    <parent link="gripper"/>
    <child link="moving_jaw_so101_v1"/>
    <axis xyz="0 0 1"/>
    <limit effort="10" velocity="10" lower="-0.261799" upper="1.74533"/>
  </joint>
  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
  <joint name="5" type="revolute">
    <origin xyz="-2.77556e-17 -0.0611 0.0181" rpy="1.5708 2.18394e-16 3.14159"/>
    <parent link="wrist"/>
    <child link="gripper"/>
    <axis xyz="0 0 1"/>
    <limit effort="10" velocity="10" lower="-2.79253" upper="2.79253"/>
  </joint>
  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
  <joint name="4" type="revolute">
    <origin xyz="-0.1349 0.0052 3.21791e-16" rpy="-1.11022e-16 1.11022e-16 -1.5708"/>
    <parent link="lower_arm"/>
    <child link="wrist"/>
    <axis xyz="0 0 1"/>
    <limit effort="10" velocity="10" lower="-1.65806" upper="1.65806"/>
  </joint>
  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
  <joint name="3" type="revolute">
    <origin xyz="-0.11257 -0.028 2.29417e-16" rpy="-2.26208e-15 -1.3739e-15 3.14159"/>
    <parent link="upper_arm"/>
    <child link="lower_arm"/>
    <axis xyz="0 0 1"/>
    <limit effort="10" velocity="10" lower="-3.22886" upper="0.0872665"/>
  </joint>
  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
  <joint name="2" type="revolute">
    <origin xyz="-0.0303992 -0.0182778 -0.0542" rpy="1.5708 8.18789e-16 3.14159"/>
    <parent link="shoulder"/>
    <child link="upper_arm"/>
    <axis xyz="0 0 1"/>
    <limit effort="10" velocity="10" lower="-0.174533" upper="3.31613"/>
  </joint>
  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
  <joint name="1" type="revolute">
    <origin xyz="0.0207909 -0.0230745 0.0948817" rpy="-3.14159 6.03684e-16 1.5708"/>
    <parent link="base"/>
    <child link="shoulder"/>
    <axis xyz="0 0 1"/>
    <limit effort="10" velocity="10" lower="-1.91986" upper="1.91986"/>
  </joint>
  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
  <default>
    <default class="sts3215">
      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
      <joint damping="0.60" frictionloss="0.052" armature="0.028"/>
      <position kp="17.8" kv="0.0" forcerange="-3.35 3.35"/>
    </default>
    <default class="backlash">
      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
      <joint damping="0.01" frictionloss="0" armature="0.01" limited="true" range="-0.008726646259971648 0.008726646259971648"/>
    </default>
  </default>
</robot>

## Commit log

2024-05-10 Release 1.0
    Print orientations should be correct to minimse supports.
    [Print_SO_ARM100_05 - Base_03-1.STL, Print_SO_ARM100_05 - Moving_Jaw_04b-2.STL, Print_SO_ARM100_05 - Removable_Jaws_01-1.STL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]
2024-05-10 Delete Print_SO_ARM100_05 - SO_ARM100_06-2.STL
    Slightly too long
    [Print_SO_ARM100_05 - SO_ARM100_06-2.STL]
2024-05-10 Correct length of arm for standard wires
    The wires between the servos are only 15cm length.
    [Print_SO_ARM100_05 - SO_ARM130_06-2.STL]
2024-05-10 Delete Print_SO_ARM100_05 - SO_ARM130_06-2.STL
    Wrong file!
    [Print_SO_ARM100_05 - SO_ARM130_06-2.STL]
2024-05-10 Correct length of arm for standard wires
    The supplied wires are 15cm long, this should be just ok in the rear limit. To be tested!
    [Print_SO_ARM100_05 - SO_ARM130_06-2.STL]
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2024-05-13 Update to clear servo insertion
    [Print_SO_ARM100_05 - Wrist_Roll_Pitch_04b-1.STL]
2024-05-13 Update to stl files after first build
    [Print_SO_ARM100_05 - SO_ARM130_06-2.STL, Print_SO_ARM100_05 - SO_ARM130_06b-2.STL, Print_SO_ARM100_05 - Wrist_Roll_05d-1.STL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]
2024-05-13 Update short (100) arm part for less supports during printing.
    [Print_SO_ARM100_05 - SO_ARM100_06-1.STL, Print_SO_ARM100_05 - SO_ARM100_06b-1.STL]
2024-05-13 Renamed version to match CAD
    [Print_SO_ARM100_05a - Base_03-1.STL, Print_SO_ARM100_05a - Moving_Jaw_04b-2.STL, Print_SO_ARM100_05a - Removable_Jaws_01a.STL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]
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2024-05-13 update pointy removable jaws
    [Print_SO_ARM100_05c - Removable_Jaws_01d-1.STL]
2024-05-16 Create Changelog
    To keep track of updates brief descriptions of changes will be added here.
    The naming convention tracks iterations of both the CAD and how it is printed.
    The robot arm is modelled in the final assembled configuration to check clearances.
    To print though, all the CAD is placed in a new assembly to generate stl files with the correct orientation for support free printing and also files with mulitple parts.
    Slicers should not generate support for slopes over 45 from the horizontal or less than 3mm squared for minimal supports.
    For example Print_SO_ARM100_05c - Wrist_Roll_Pitch_04c-1
    Print_SO_ARM100_5c is the assembly for printing.
    Wrist_Roll_Pitch_04c is th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
2024-05-16 update folder name Jaws to jaws
    [Print_SO_ARM100_05a - Moving_Jaw_04b-2.STL, Print_SO_ARM100_05a - Removable_Jaws_01a.STL, Print_SO_ARM100_05a - Wrist_Roll_05e-1.STL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]
2024-05-17 Cleanup repo (#1)
    * Add .gitignore
    * Update readme
    * Rename stl_files -> parts
    * Rename files to shorter names
    * Organize by folders
    * Rename changelog
    * Set minor version v1.2.0 -> v0.2.0, change date format
    * Rename files
    * Update Changelog
    [Arm_100.STL, Arm_130.STL, Base.STL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]
2024-05-17 Fix removable jaw `Tip_c`
    [Tip_c.STL]
2024-05-21 URDF exported from Solidworks, probably has errors
    [Base.STL, Fixed_Gripper.STL, Lower_Arm.STL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]
2024-05-21 URDF tested correct
    [Base.STL, Fixed_Gripper.STL, Lower_Arm.STL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]
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2024-09-25 New URDF
    URDF for SO_5DOF_ARM100_8j
    Meshes and geometry tested correct with online URDF viewer on Chrome: https://gkjohnson.github.io/urdf-loaders/javascript/example/bundle/index.html
    No limits set.
    [Base.STL, Fixed_Jaw.STL, Lower_Arm.STL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]
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2024-09-30 Uploaded Alternative Leader Controllers
    [Small_Leader_Test_01.STL, Trigger_04g.STL]
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2024-09-30 Bug fix
    [Small_Leader_Test_01.STL, Small_Leader_Test_01a.STL]
2024-10-02 S0_7DOF
    URDF generated from a draft of the 7DOF version for the HOPELite to allow modeling to begin.
    Dimensions should not change much, if at all as the design converges to a printable state.
    [Base.STL, End_Servo.STL, Forearm.STL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]
2024-10-02 Added .SLDASM to folder name
    [Base.STL, End_Servo.STL, Forearm.STL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]
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2024-11-25 Add 3D printing files for the BambuLab A1 Mini
    [Print_Follower_SO_ARM100_08k_UP_BambuLabA1Mini_part1.STL, Print_Follower_SO_ARM100_08k_UP_BambuLabA1Mini_part2.STL, Print_Leader_SO_ARM100_08k_UP_BambuLabA1Min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]
2025-01-26 complete file to print SO-100 arms on the Bambu P1P printer
    i've printed at least 6 arms successfully and have all the settings
    dialed in for efficiency. Sharing in case its helpful to others.
    [Print_Follower_Bambu_P1P.3mf, Print_Leader_Bambu_P1P.3mf]
2025-01-27 add individual step files, clean up directory
    [Base_08q.step, Base_attachment.step, Motor1_holder.step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]
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2025-02-24 README: clean-up/fix links to various 3d printer files
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2025-03-18 fix duplicate part in bambu print files
    [Print_Leader_Bambu_P1P.3mf]
2025-03-19 feat: add helper piece
    Make it easier to mount your SO100
    [mount_helper v2.stl]
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2025-03-21 Rename folders and update wrist cam options in main README
    [Camera_Holder_Alternate_MF.stl, Updated_Wrist_Camera_Insert.stl, Webcam_Mount_Wrist v2.stl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]
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2025-04-01 Feat/printing (#44)
    * add print guide
    * Add ref to print md
    * Add back plate with m2.5 holes
    * update wrist mount
    * add craftcloud
    * remove prusaworld
    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
    [WaveShare_Mounting_Plate.stl]
2025-04-14 Optional overhead camera mount for single and bi-manual setups (#59)
    * added STL files and empty README
    * basic README
    * more text
    * Update README.md
    * Update README.md
    * Update README.md
    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
    [arm_base.stl, cam_mount_bottom.stl, cam_mount_top.stl]
2025-04-22 README: clean up Optional Hardware and Software sections (#61)
    README's optional hardware section lacked organization and imagery.
    - sorted in alphabetical order
    - added proper links to each item (i.e. README.md) if available, otherwise the stl file)
    - added small preview image of each item
    Test Plan:
    - clicked on *every* link in the optional hardware section
    - verified that the images are displayed correctly
2025-04-22 Add a plugin UVC camera mount (#52)
    * Add plugin UVC module
    * A link in README
    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
    [SO-ARM100 Plug camera.step, SO-ARM100_Plug_camera.stl]
2025-04-28 Update (#67)
    * Add SO101, cleanup repo
    * align images to middle
    * align main readme
    * update prices in table
    * update links
    * Update links alibaba with new geared motors
    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
    [Base.STL, Base_08q.step, Base_SO101.step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]
2025-04-28 Feat/add urdf (#70)
    Add back in Urdf so100
    [Base.STL, End_Servo.STL, Fixed_Gripper.STL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]
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2025-05-19 Add 32x32 wrist camera adapter for the SO-101 (#85)
    * add s101 wrist camera mount 3d models
    * add s101 wrist camera mount assembly instructions
    * add note about optional so101 wrist camera to readme
    [SO-ARM101_camera_wrist_mount.step, SO-ARM101_camera_wrist_mount.stl]
2025-05-19 Add old and new simulation files for so101 (#86)
    [so101_new_calib.urdf, so101_old_calib.urdf]
2025-05-21 Update URDF (#83)
    * fix SO101 URDF, add SO100 URDF, remove unnecessary SLDASM files
    * update SO100 URDF
    * update README
    [Base.STL, Base.stl, Base_Motor.stl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]
2025-05-22 [Optional Hardware] improve overhead camera to support common camera modules (#88)
    * two overhead cam projects, one for webcam and one for 32x32 cam module
    * minor fix
    * fix for @pkooij comment
    (i can't actually see his comment, but from where
    pkooij's link goes to i figure it has to do with making sure
    the "Optional Hardware" section is collapsed by default in README, so made that change)
    ---------
    [arm_base.stl, cam_mount_bottom.stl, cam_mount_middle.stl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]
2025-05-23 Update docs: Add missing URDF plugin link (#91)
    * Explain urdf plugin
    * Add picture
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2025-06-11 First test with 0.2mm clearance between parts
    May not work!
    As in may not be able to move the parts once the supports are removed. Tests indicate it should but I find it hard to believe. 0.2mm is three human hairs of clearance only.
    Feedback welcome from other prints on different machines and settings.
    [Mini_SO_100_01f.STL]
2025-06-11 Corrected orientation
    [Mini_SO_100_01g.STL]
2025-06-13 For Bambu
    Bambu A1, 0.4mm nozzle, 0.2mm layers, >30 supports, PLA+
    [Mini_SO_100_01g.3mf]
2025-06-18 [Optional Files] Compliant gripper parts. (#103)
    * [Optional Files] Compliant gripper parts.
    Includes both STEP and STL files for the leader arm compliant gripper. Prototypes were printed at 20% infill with TPU filament on a BambuLabs printer.
    * Removed STEP files and put STL files in a folder
    * Created new folder for compliant gripper stl files
    * Delete Optional/Compliant_Moving_Jaw_SO101.step
    * Delete Optional/Compliant_Moving_Jaw_SO101.stl
    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
    [Compliant_Moving_Jaw_SO101.stl, Compliant_Wrist_Roll_Follower_SO101.stl]
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2025-06-23 Add Wrist Camera Mount for Intel® RealSense™ D435/D435I (+Vinmooog adapter) (#110)
    * Create D435_Mount README.md
    * Add files via upload
    * Add files via upload
    * Update D435 README.md
    * Add D435 mount images
    * Update D435_Mount README.md
    Add link to stl files in the README
    * Update README.md to add D435 camera mount
    Fix D435_Vinmooog_adapter.stl link
    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
    [D435_Vinmooog_adapter.stl, Wrist_cam_mount_RealSense_D435.stl]
2025-06-25 Updated the new so101 calibration urdf with fixed direction and frame (#106)
    * (update) updated the new so101 calibration urdf with fixed direction and frame names
    * Re-integrate the latest changes in the urdf"
    1- remove package in assets path
    2- add material back
    3- add encoding style in xml header
    * Add back blocks related to transmissions
    * Place back the pose of the so101_new_calib to adhere to the same conventions used in the other description files
    * add ctrlrange to the xml file to control each joint of so101_new_calib over the full range of motion
    * shift joint(3) elbow flex by five degrees to adhere to the offset on the real robot
    * correct joint 3 offset
    * style(joints na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
    [so100.urdf, so101_new_calib.urdf, so101_old_calib.urdf]
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2025-06-30 Add optional 4040 aluminum profile base mount (#113)
    * Create README.md for 4040_Base_Mount
    * Add images for 4040_base_mount
    * Update README.md for 4040_base_mount
    * Upload stl/ and step/ for 4040_base_mount
    * Add 4040 base mount in addons
    Renamed section from "Raised Leader Base" to "Mounting Bases"
    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
    [4040_base_mount.step, 4040_base_mount.stl]
2025-06-30 updated one-piece wrist camera for SO-101 (#114)
    * updated integrated UVC camera holder for SO-101
    * updated image
    * updated descriptions
    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
    [Camera_Holder_Alternate_MF.stl, Wrist_Cam_Mount_32x32_UVC_Module_SO100.stl]
2025-07-02 fix(urdf): fixing multiple issues related to the last URDF update (#117)
    * Adding _link suffix to link names to avoid duplicates
    * Removing unused intermediate base frame
    * Fixing origin frame offsets
    [so101_new_calib.urdf]
2025-09-02 Update Seeed Studio mounting plate for SO-101 (#127)
    [Seeedstudio_Mounting_Plate_SO101.step, Seeedstudio_Mounting_Plate_SO101.stl]
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
